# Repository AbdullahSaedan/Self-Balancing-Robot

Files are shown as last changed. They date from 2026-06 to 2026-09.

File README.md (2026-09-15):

# Self-Balancing Robot - Control Systems Project

https://github.com/user-attachments/assets/34fe275d-3d88-4c13-a9c5-a07f3246fb1b

A two-wheel self-balancing robot built from scratch — from first-principles dynamic
modelling and simulation to embedded control on hardware.

## Project Stages

-  **Stage 0** - Simulation of a single body pendulum: PID control, gain tuning, documented results
- **Stage 1** - Full coupled cart-pole simulation: explicit equations of motion, cascaded PID, pole placement analysis, state feedback control
-  **Stage 2** - Hardware design: Component selection, mechanical design, CAD, measurment of physical parameters
-  **Stage 3** - Embedded implementation: Microcontroller, IMU integration, sensor filtering, control on hardware, tuning

## Skills Demonstrated

- Dynamic modelling and equations of motion from first principles
- State-space modelling and full-state feedback control
- Pole placement design and closed-loop stability analysis
- PID control design with anti-windup and derivative on measurement
- Discrete-time simulation in Python
- Gain tuning and performance analysis
- Engineering documentation
- Complementary Filtering
- Gain scheduling

## Repository Structure

```
analysis/     Pole placement and recovery-limit analysis scripts
simulation/   Plant model, controllers, and simulation entry points
hardware/     Chasis Design, CAD and build documentation
embedded/     Arduino firmware - bringup and control
docs/         Derivations and results for every stage
tools/        Log parsing and plotting scripts
logs/         Raw captured runs from the robot
tools/        Log parsing and plotting scripts
```

## Results - Stage 0

*Nominal tuning — stable convergence within 0.5 seconds*

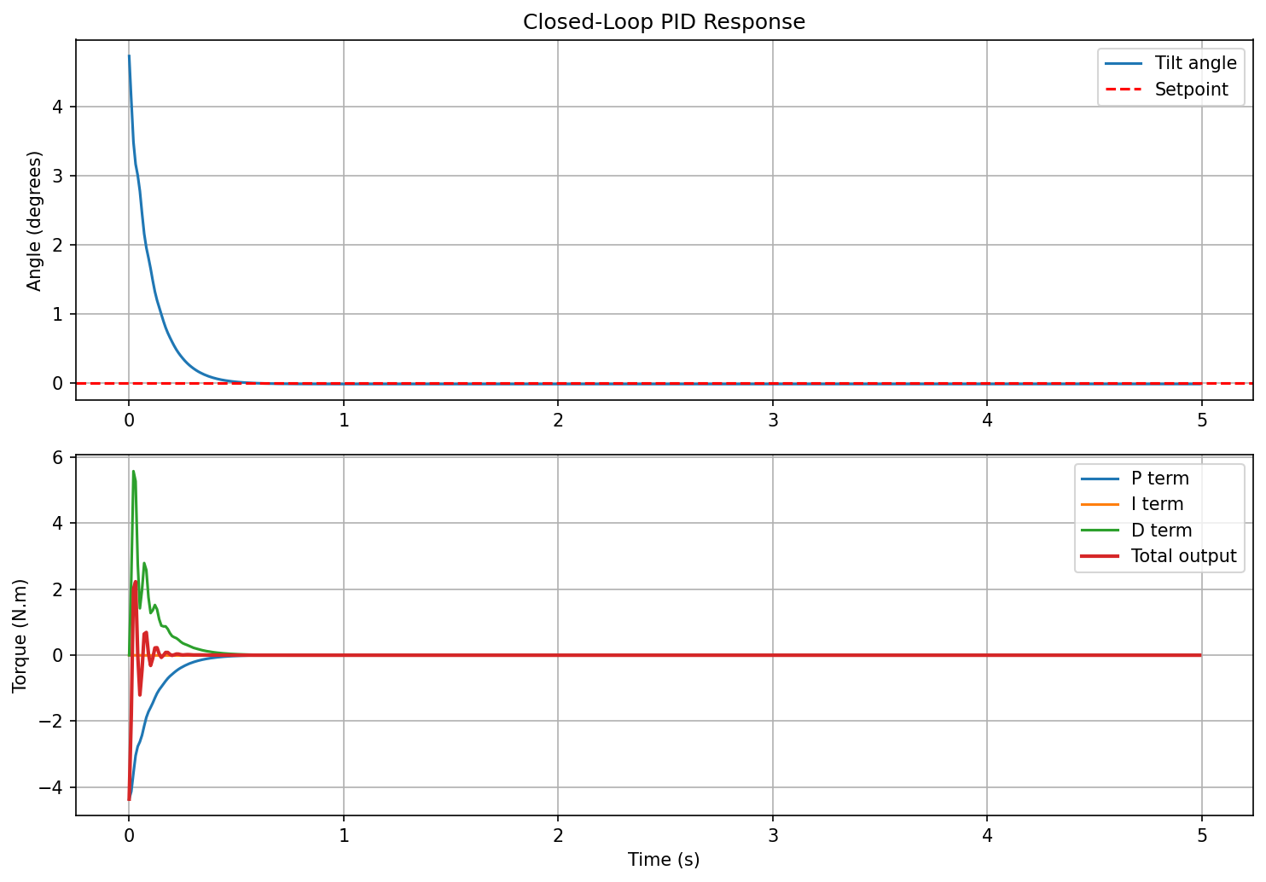
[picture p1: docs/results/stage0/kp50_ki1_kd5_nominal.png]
<br>

*Controller recovery limit — 5 N.m torque limit, all angles recovered but only up to 10° converge to zero*

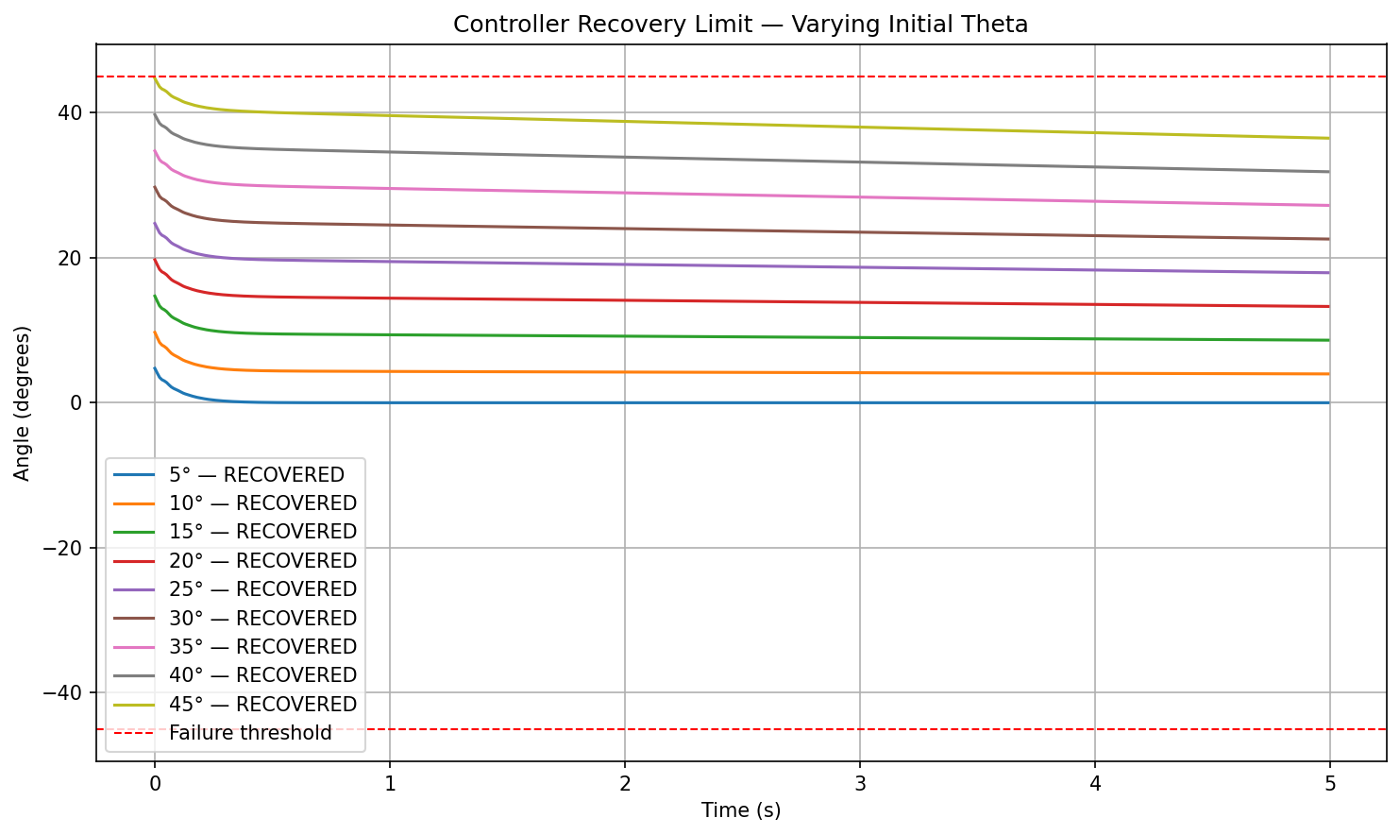
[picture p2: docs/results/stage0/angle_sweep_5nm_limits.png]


[View full Stage 0 results](docs/results/stage0/README.md)

## Results - Stage 1

*Cascaded PID — oscillates, does not fully converge*

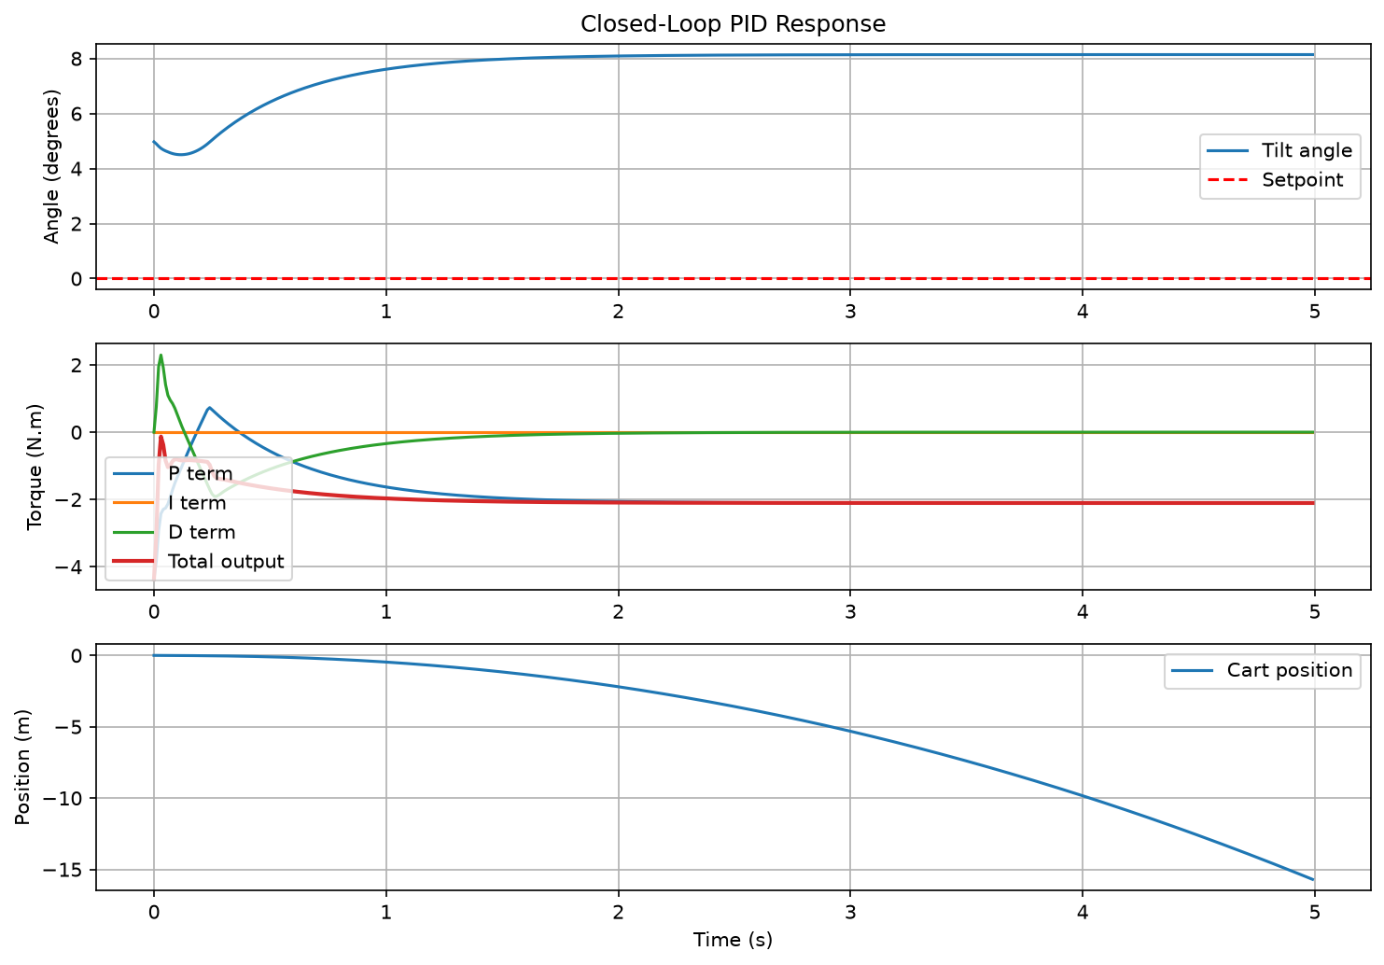
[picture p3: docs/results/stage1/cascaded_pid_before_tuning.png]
<br>

*State feedback with pole placement — converges to zero*

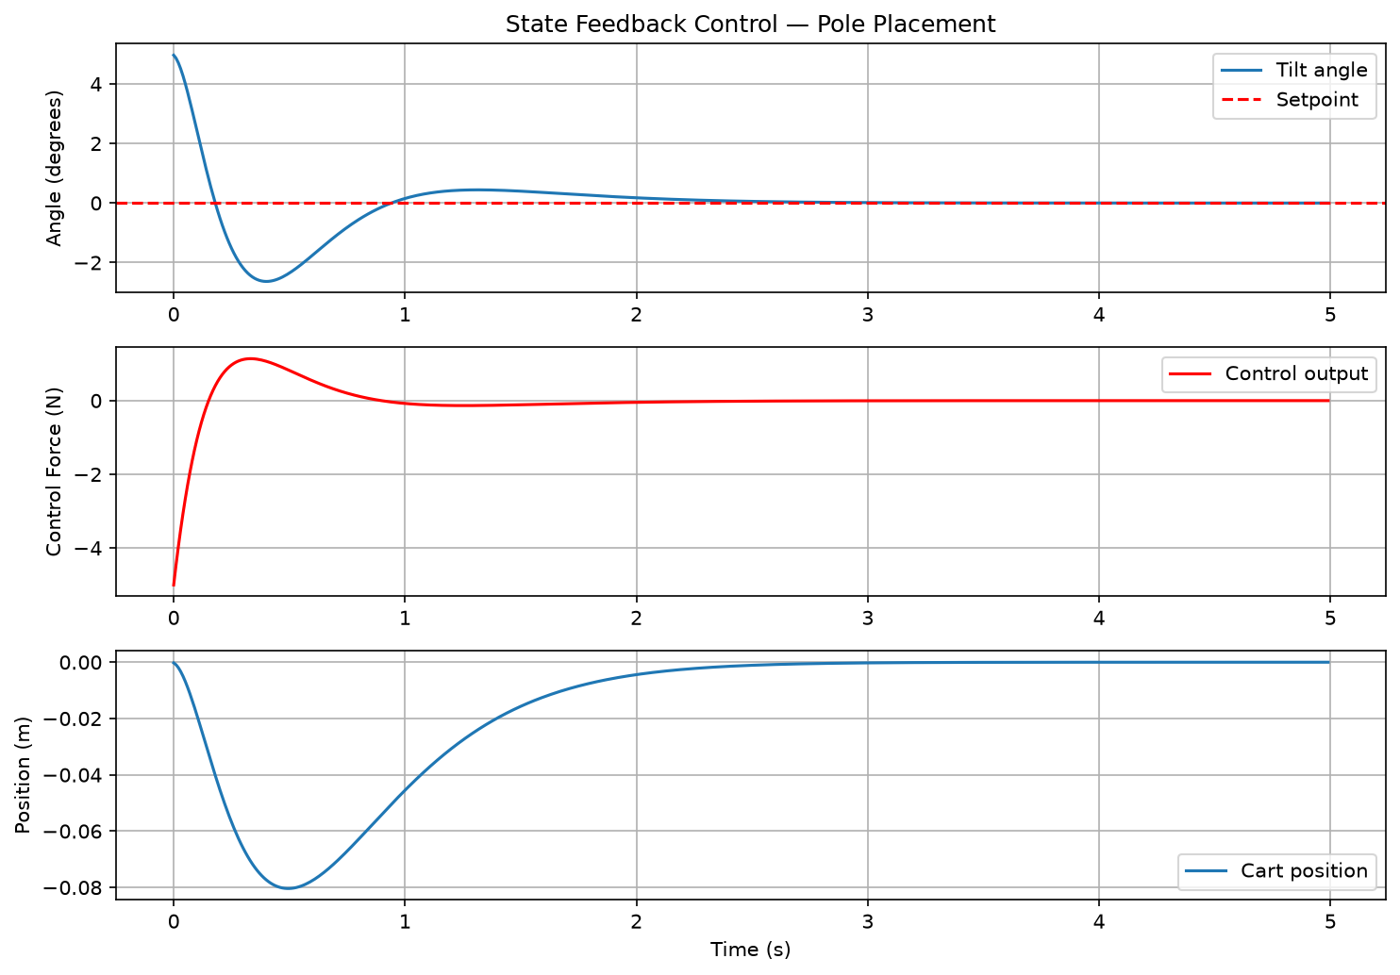
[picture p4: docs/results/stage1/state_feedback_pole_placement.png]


[View full Stage 1 results](docs/results/stage1/README.md)

## Results - Stage 2

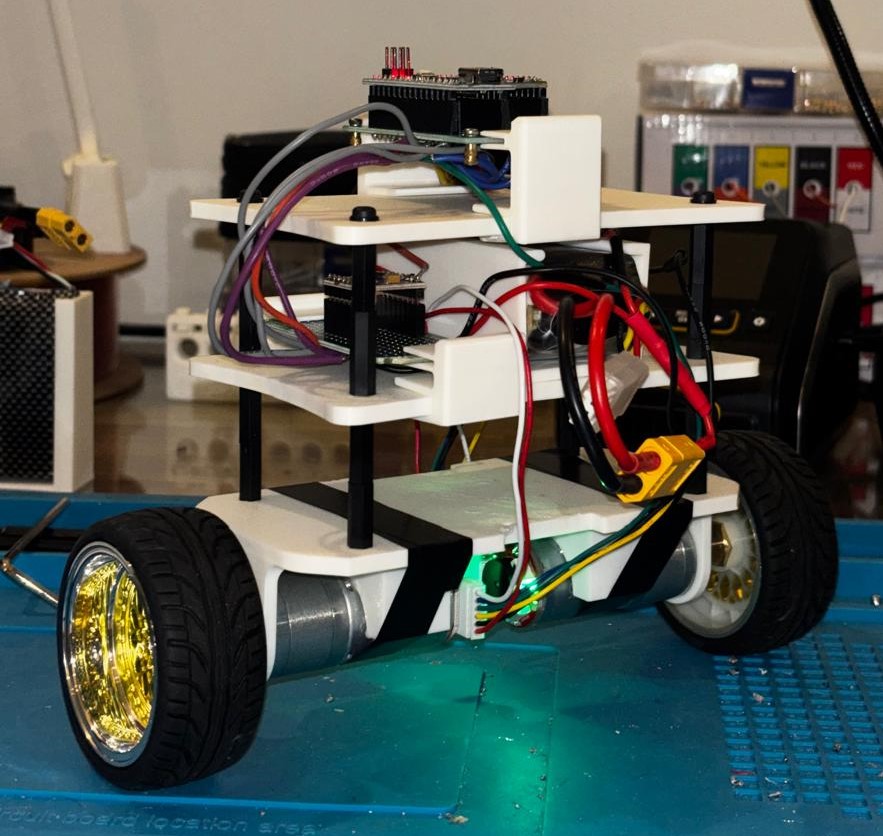
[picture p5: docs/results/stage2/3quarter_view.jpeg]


### Measured Physical Parameters

| Parameter | Symbol | Assumed (Stage 1) | Measured | Method |
|---|---|---|---|---|
| Body mass | m | 0.50 kg | 0.565kg | Scale |
| Wheel/base mass | M | 0.30 kg | 0.056kg | Scale |
| Pivot to COM height | L | 0.10 m | 0.043 | moment balance |
| Body inertia about COM | I | 0.006 kgm² | 0.00082 kgm² | Compound pendulum, 20 swings |

Stage 1 gains were recomputed from the measured values before hardware, this was implemended in stage 3.

[View full Stage 2 results](docs/results/stage2/README.md)

## Results - Stage 3

*Steady-state balancing - holds within ±2.0°, using under 16% of actuator authority*

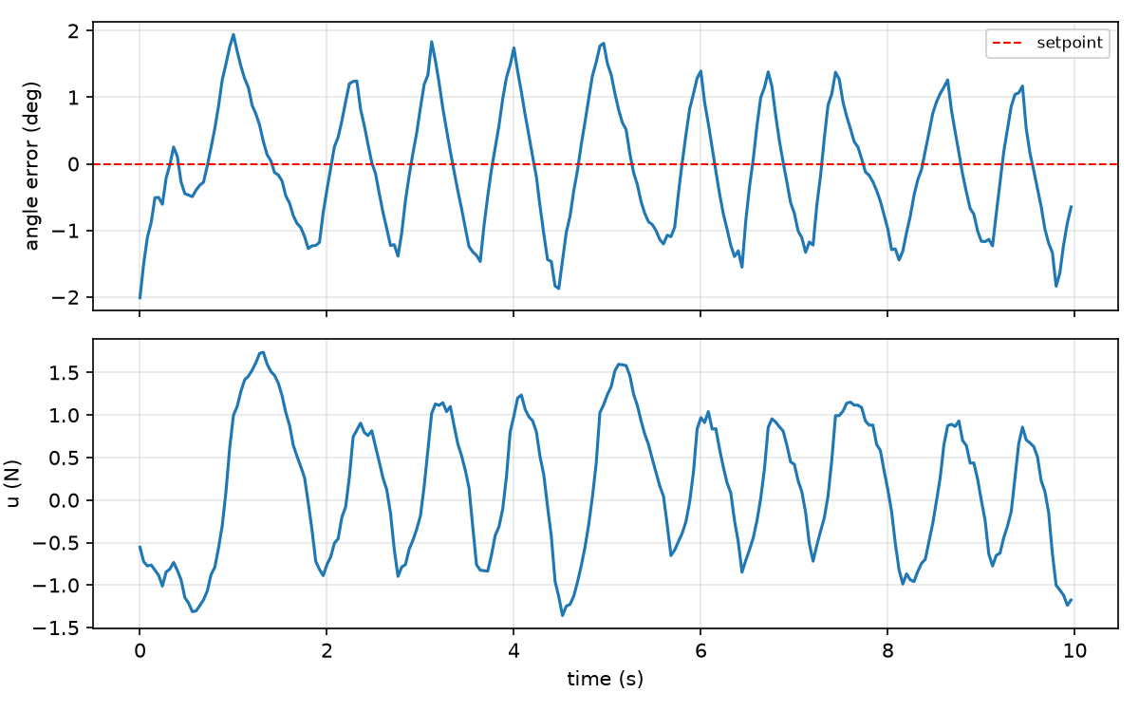
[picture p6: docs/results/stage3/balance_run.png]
<br>

*Disturbance rejection - scheduled velocity gain recovers from a 9.4° push, fixed gain falls from 2.2°*

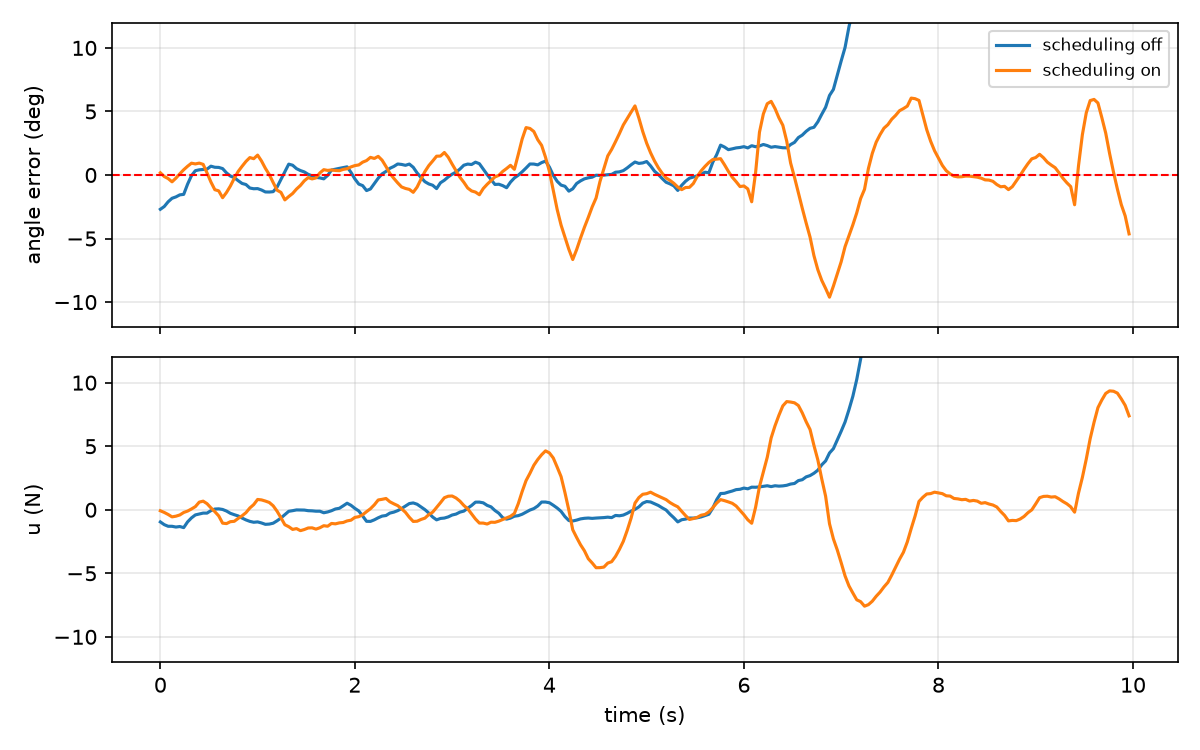
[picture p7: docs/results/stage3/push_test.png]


### Actuator Characterisation

U_MAX was measured at 11.1 ± 0.13 N by step response identification, against a
datasheet guess of 4.0 N. The same data revealed back-EMF drag of 26 N·s/m
missing from the Stage 1 plant, which was added before the gains were recomputed.

Three of the four gains are used exactly as derived from pole placement. The
velocity gain is the exception, reduced from 27 to 16 and scheduled back up
above 0.15 m/s.

[View full Stage 3 results](docs/results/stage3/README.md)

## Setup

Requires Python 3.12 or later.

```bash
git clone https://github.com/AbdullahSaedan/Self-Balancing-Robot.git
cd Self-Balancing-Robot
pip install -r requirements.txt
```

Run a simulation:

```bash
python simulation/simulate.py
python simulation/simulate_state_feedback.py
```

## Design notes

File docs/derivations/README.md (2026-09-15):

**Note:** this model has a single actuator. The applied horizontal force F is the only control input; there is no independent pivot torque. The motor's effect on the pendulum enters through the coupling term -mlẍcosθ rather than as a direct torque about the pivot. In the simulation code this input is named u.

# Equations of Motion

Derived from first principles using the Lagrangian method.

## Cart equation (horizontal motion)
(M+m)ẍ - mLθ̈cosθ + mLθ̇²sinθ = F(t)

## Pendulum equation (rotational motion)
(I+mL²)θ̈ - mLẍcosθ - mgLsinθ + bθ̇ = 0

Where:
- I = moment of inertia of the pendulum about its centre of mass (kg.m²)
- M = cart/wheel mass (kg)
- m = pendulum body mass (kg)
- L = distance from pivot to centre of mass (m)
- θ = angle from vertical (rad)
- F(t) = applied motor force (N)
- b = viscous damping coefficient (N.m.s/rad)

These are the full nonlinear coupled equations.
Stage 0 used a simplified single-body approximation as a first step.
These full coupled equations are implemented in Stage 1.

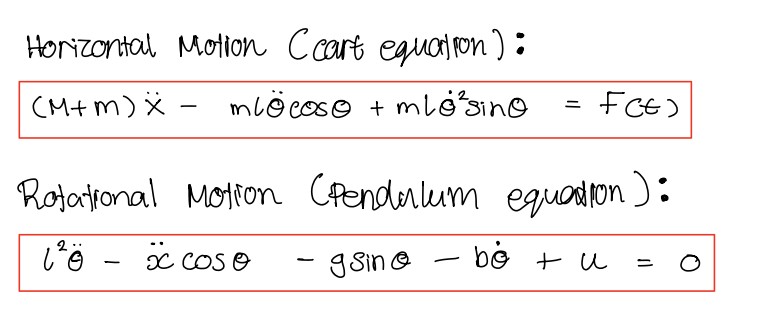
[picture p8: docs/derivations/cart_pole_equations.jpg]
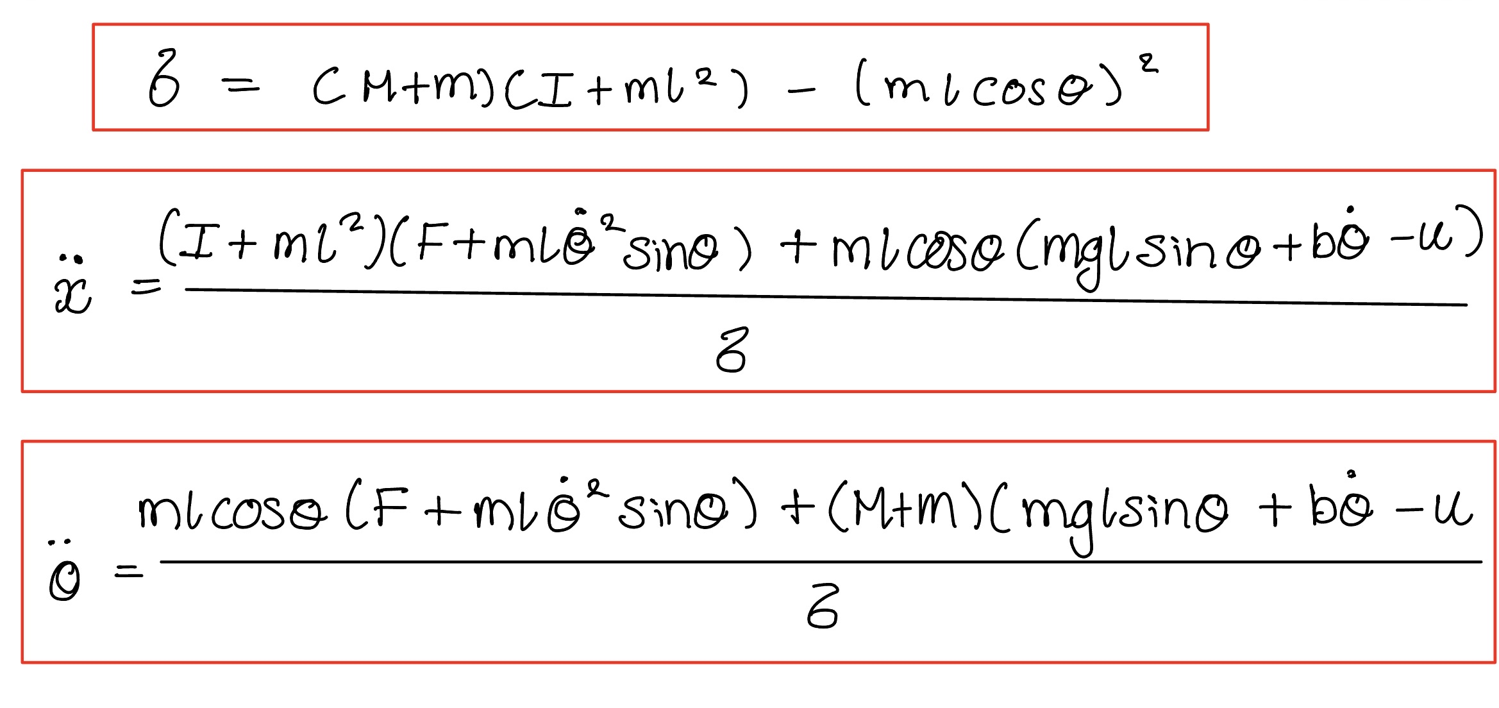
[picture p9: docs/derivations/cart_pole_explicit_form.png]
 

*Note: these images show the original hand derivation, which contained sign errors in the damping and centrifugal terms and incorrectly treated the control input as an independent pivot torque. The errors were identified through a dimensional consistency check and a physical sanity check on the open loop pole location, and propagated into the simulation code before correction. The equations above supersede the images.*

## Explicit form for simulation

The coupled equations above were solved simultaneously to eliminate the coupling terms and giving explicit expressions for both ẍ and θ̈ .

A shared denominator δ appears naturally from the algebra:

δ = (M+m)(I+mL²) − (mLcosθ)²

This represents the coupled inertia of the system. It varies with θ because the mechanical coupling between the cart and the pendulum changes with the angle.

ẍ = [(I+mL²)(F − mLθ̇²sinθ) + mLcosθ(mgLsinθ − bθ̇)] / δ

θ̈ = [mLcosθ(F − mLθ̇²sinθ) + (M+m)(mgLsinθ − bθ̇)] / δ

Where:
- δ = coupled inertia denominator
- I = moment of inertia (kg.m²)
- All other variables as defined above

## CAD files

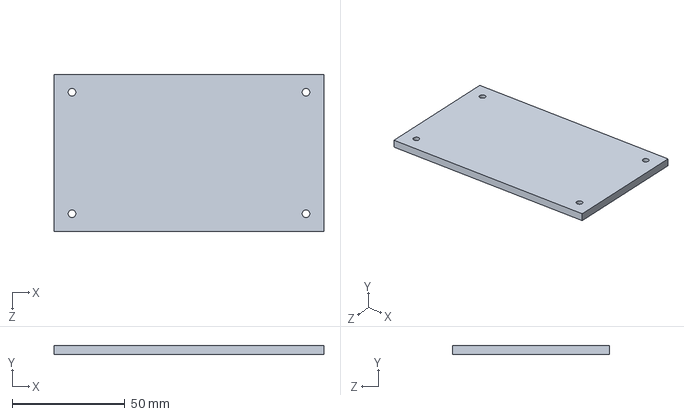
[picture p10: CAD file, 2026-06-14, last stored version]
hardware/CAD/platform.SLDPRT
120.0 x 4.00 x 70.0 mm

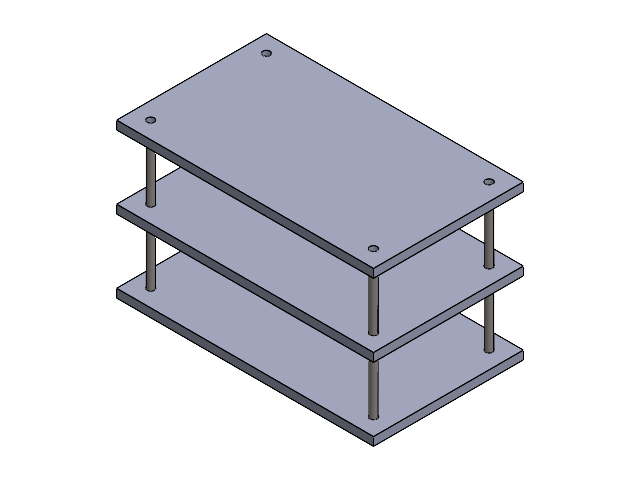
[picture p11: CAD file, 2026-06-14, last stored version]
hardware/CAD/chassis_assembly.SLDASM
platform x 3
socket head cap screw3_iso x 8

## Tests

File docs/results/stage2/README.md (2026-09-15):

# Hardware Design - Stage 2

## Build

*Assembled robot — three-quarter, top and side views*


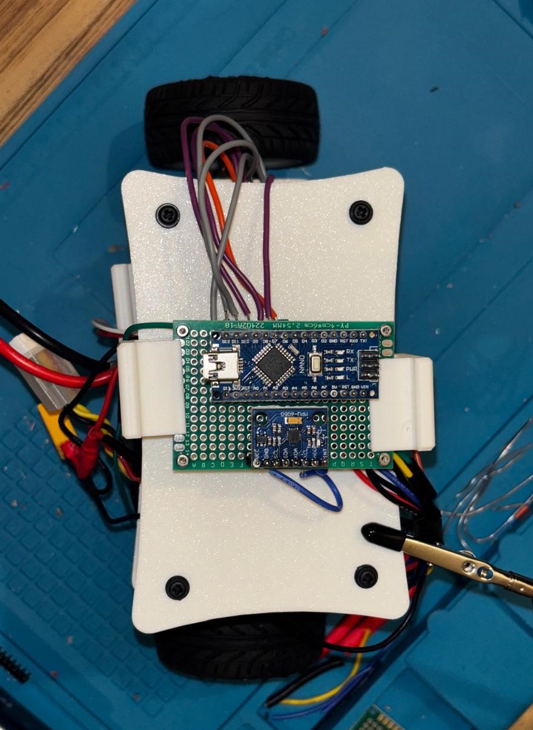
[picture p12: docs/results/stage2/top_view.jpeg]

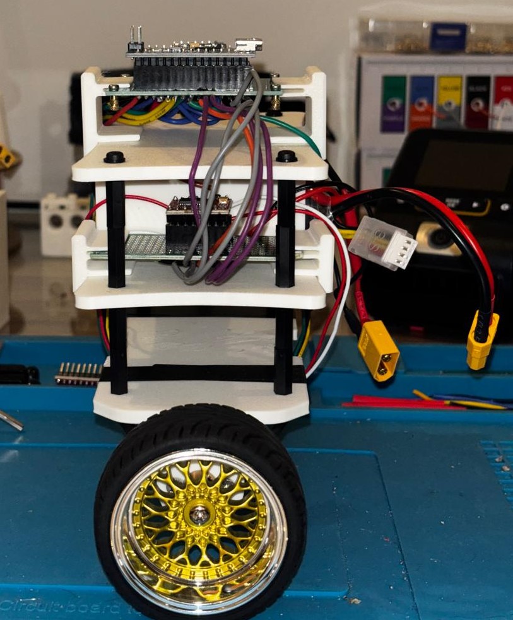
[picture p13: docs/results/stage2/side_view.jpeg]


## Component Selection

| Component | Qty | Key spec | Why chosen |
|---|---|---|---|
|**LM2596** |**1** |**Not in final build - see why under 'Electronics''**, ||
|Arduino Nano |1 |ATmega328P chip, 16MHz, 5V |Small footprint, widley available |
|MPU6050 IMU |1 |6-axis (3axis accelerometer, 3axis gyroscope), I2C |Measures both acceleration and rotation rate|
|TB6612FNG Driver |1 |Dual-channel, 1.2A continuous - 3.2A peak, 2.5-13.5V motor supply |Lower voltage drop than common alternatives (Important with 7.2v battery)|
|JGA25-370 |2 |12V, 170RPM - no load, integrated encoder, 1.2-1.8 stall |Integrated quadrature encoders provide the wheel position and velocity states required for full state feedback |
|Wheels - 65mm Diameter |2 |Rubber, 65mm diameter |Rubber for traction|
|2S LiPo |1 |7.4V, 1600mAh |Voltage within drivers range |

## Mechanical Design
### Chassis Layout

The chasis is a three-platform stack. The bottom platform has motor mounting brackets built into it, holding the motors beneath it, with the battery carried ontop. The middle platform holds the motor driver and buck converter. The top platform carries the perfboard with the Arduino nano and IMU, mounted centrally.

The battery was originally intended to be on the middle platform in order to avoid lowering center of mass, however a decision was made to mount it into a printed bracket for removability. The bracket takes up more space than the battery alone so space was only found for it in the bottom platform, this works against the stacks layout intent of raising it but was accepted in exchange for a removable battery.

### Printed Parts

*CAD source files for the chassis were lost in a hardware issue and have not been recreated. Printed parts remain in use and physical parameters were measured from the build assembly*

**Bottom Platform.** Printed as a single piece with the motor mounting brackets included in the geometry rather than as separate bonded parts. The brackets locate the motors at the front of the body only.

**Motor rear supports.** The integral brackets hold the motors at one end, leaving the rear of each motor unsupported. Because the motors are back-heavy, this caused the rear ends to slack under their own weight. A support was printed for each motor with a semicircular cutout matching the motor barrel radius, bonded to both the platform and the motor body. This constrains the rear of the motor and eliminates the issue.

**Battery bracket.** A printed enclosure glued to the bottom platform, holding the LiPo. The front face is left open so the battery slides in and out, and the top face is reduced to narrow lips along each side, retaining the battery vertically while leaving most of the top open to reduce excessive friction.

**Perfboard clips.** The top perfboard is populated with wiring on its underside, so it cannot sit flush against the platform. Friction-fit clips were printed to engage both the platform and the perfboard, standing it off far enough to clear the wiring beneath. Using a friction fit rather than glue means the perfboard can be lifted off for access without breaking the mounting. 2 clips were added one on each side near the edge of the platform.

### Assembly
The three platforms are joined by nylon M3 standoffs at [X]mm spacing.

The middle perfboard is mounted using four small M3 standoffs, glued to the platform and passing through the 4 corner holes with a screw ontop of each. The top perfboard uses friction-fit clips instead, which was the later and better approach since it avoids the bonded joint and allows the board to be lifted off. However, omponents on both boards are socketed on headers rather than soldered directly, so they remain accessible for replacement regardless of how the board itself is mounted.

Motors are fastened into the integral brackets with screws.

## Electronics
### Power Architecture
An LM2596 buck converter originally supplied the 5V rail. It was removed. Taking VCC from the Nano's own 5V rail means the driver's logic supply and its logic signals always come from the same source; with a separate converter there is a state in which battery is disconnecte and USB is connected, where the Nano drives the driver's inputs while its VCC sits at 0V. Two motor drivers were lost before this was identified.

The 2S LiPo supplies two separate rails. Motor power is taken directly from thebattery to the TB6612FNG's VM input. The battery also feeds the Arduino Nano's VIN, whose onboard regulator produces the 5V rail supplying the MPU6050, the encoders, and the driver's logic input (VCC) — allowing one battery to fulfil both voltage requirements.

The rails are also separated because, motors need rapidly switching currents which causes noise. Sharing a supply between the motors and the sensor electronics would couple that switching noise into the IMU readings, which the control loop depends on.

All subsytems share a common ground. This is because the driver interprets the Nano logic reletive to its own ground reference, so in order to keep the logic consistent they must have the same reference point.

The IMU is mounted on the top platform, physically separated from the driver on the middle platform. The driver is a noise source, so distance between it and the sensor is a design choice.

### Wiring
#### Arduino Nano

| Pin | Connects to | Function |
|---|---|---|
| D2 | Motor A encoder channel A | Encoder input |
| D3 | Motor B encoder channel A | Encoder input |
| D4 | Motor A encoder channel B | Encoder input |
| D5 | Motor B encoder channel B | Encoder input |
| D6 | TB6612 STBY | Driver enable |
| D7 | TB6612 AIN1 | Motor A direction |
| D8 | TB6612 AIN2 | Motor A direction |
| D9 | TB6612 PWMA | Motor A speed |
| D10 | TB6612 PWMB | Motor B speed |
| D11 | MPU6050 INT | IMU interrupt |
| D12 | TB6612 BIN1 | Motor B direction |
| D13 | TB6612 BIN2 | Motor B direction |
| A4 | MPU6050 SDA | I2C data |
| A5 | MPU6050 SCL | I2C clock |
| D0, D1 | Reserved for USB serial | Not connected |

#### Power

| From | To | Wire |
|---|---|---|
| Battery + | TB6612 VM |
| Battery + | Buck IN+ |
| Battery - | Buck IN- |
| Buck OUT+ (5V) | TB6612 VCC |
| Buck OUT+ (5V) | Nano 5V pin |
| Buck OUT+ (5V) | Encoder VCC, both motors |
| Buck OUT+ (5V) | MPU6050 VCC |

#### Motor outputs

| TB6612 | Motor | Wire |
|---|---|---|
| AO1 | Motor A + |
| AO2 | Motor A - |
| BO1 | Motor B + |
| BO2 | Motor B - |

## Physical Parameters

| Parameter | Symbol | Assumed (Stage 1) | Measured | Method |
|---|---|---|---|---|
| Body mass | m | 0.50 kg | 0.565kg | Scale |
| Wheel mass | M | 0.30 kg | 0.056kg | Scale |
| Pivot to COM height | L | 0.10 m | 0.043 | moment balance |
| Body inertia about COM | I | 0.006 kgm² | 0.00082 kgm² | Compound pendulum, 20 swings |

[View Stage 3 results](../stage3/README.md)

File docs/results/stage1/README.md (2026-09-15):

# Simulation Results - Stage 1

**Note on parameters:** The physical parameters used throughout Stage 1 - cart and pendulum mass, pendulum length, and the torque limit are nominal values chosen before hardware selection. They do not represent the measured properties of the robot being built. Open loop pole locations, gain values and settling times therefore describe the model rather than the physical system. Simulations will be re-run with measured parameters once characterisation is complete in Stage 2.

## Angle Only PID

With the full coupled cart-pole model implemented, the same angle-only PID from Stage 0 was tested. Unlike Stage 0 where cart motion was not modelled, the cart is now free to drift.

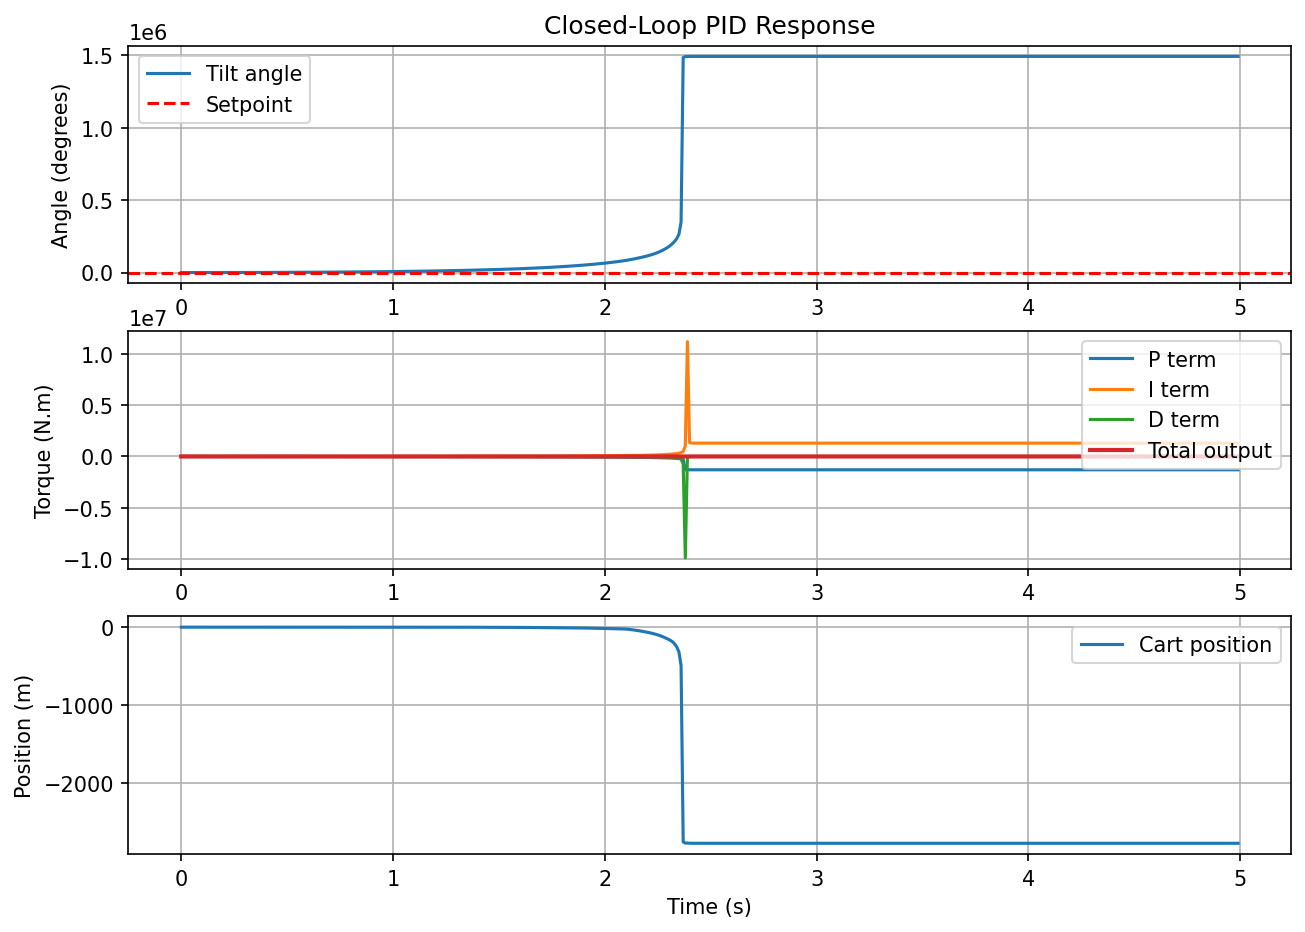
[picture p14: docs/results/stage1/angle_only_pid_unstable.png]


The system goes unstable - the angle explodes to 10⁶ degrees and the cart drifts to -2500m, essentially meaning both are heading to infinity - the pendulum has fallen.

This behaviour is expected since the PID controller is only controlling the angle and is not accounting for cart drift. This shows that a second PID is needed to control the cart's position.

## Cascaded PID - Before Analytical Tuning

To control both angle and cart position simultaneously, a cascaded PID structure was implemented. An outer position PID computes a target angle setpoint, which is fed into an inner angle PID that produces the control force. Gains were tuned manually.



The cascaded PID fails to regulate cart position. The angle settles at a constant 8.1 degrees with a constant control output of -2.1 N, while the cart accelerates away continuously, reaching -15.7m within 5 seconds. The system finds a runaway equilibrium where a constant tilt and constant force balance while the cart accelerates without bound. It is almost impossible to fully stabilise this way because correcting angle affects position and correcting position affects angle. This is because the two PIDs were designed independently without accounting for the mathematical coupling between cart and pendulum dynamics.

## Pole Placement Analysis

Before implementing state feedback, the open loop poles of the system were computed using the linearised A matrix from plant.py:

Open loop poles: [ 0, 0, 6.22, -7.89]

The positive pole (6.22) confirms the system is naturally unstable - the pendulum will fall without control. The two poles at zero correspond to the cart states, confirming the cart drifts indefinitely without correction.

Desired closed loop pole locations were arrived at iteratively. Poles must lie in the left half plane for stability, and were placed relative to the open loop unstable pole at 6.220. Successive sets were tested in simulation and evaluated on settling time and peak control force: poles placed further left converged faster but demanded more force. [-3, -4, -5, -6] was retained as the fastest response that stayed within a reasonable force budget.

The pole placement algorithm computed the required state feedback gain matrix:

K = [57.33, 8.15, -11.01, -10.83]

Where each value corresponds to the gain on θ, θ̇, x, and ẋ respectively.

## State Feedback Control - Pole Placement Result

Using the gain matrix K computed from pole placement, state feedback control was implemented in `simulate_state_feedback.py`. The control law replaces the entire cascaded PID with a single equation:

u = -(K[0]·θ + K[1]·θ̇ + K[2]·x + K[3]·ẋ)

All four states are used simultaneously to compute the control force, accounting for the coupling between cart and pendulum that the cascaded PID struggled with.



Using state feedback control stabilised the system. The angle starts at about 4.5 degrees, undershoots to -2.6 degrees, and converges to the setpoint within approximately 2.5 seconds. Peak control force is 5 N at the start of the correction, decaying to zero as the system settles. The cart moves a maximum of 0.08m from the origin before returning to it - a significant improvement over the cascaded PID, which failed to regulate position at all.

[View Stage 2 results](../stage2/README.md)

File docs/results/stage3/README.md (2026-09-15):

# Stage 3 — Embedded Implementation

Closing the loop on hardware. Bring-up constants, pin map and wiring are in Stage 2. This stage covers the actuator measurement that corrected the plant model, the recomputed gains, and the measured balancing performance.

Code was written with AI assistance for C and Arduino idiom. The control design, measurements, system identification and debugging are my own work.

## Actuator characterisation

The firmware converts force to duty as duty = u / U_MAX × 255. U_MAX is the scale factor between the newtons the controller computes and the PWM actually delivered, so an error in it multiplies every gain equally. It had been carried as a datasheet guess of 4.0 N, changed to 2.77 then later replaced by 11.1 N (see method below).

### Method

The robot was laid flat on a bottlecap used as a skid and driven from standstill at full duty, with distance logged from the encoders. Ten runs.

The step response of the drivetrain is first order. Fitting it across the full run gives v_max and τ, from which a₀ = v_max / τ. This is more reliable than measuring the initial slope by hand, where few samples and a small displacement leave the encoder noise dominating.

| Parameter | Fitted | Meaning |
|---|---|---|
| a₀ | 17.7 m/s² | Acceleration at t = 0, full force available |
| v_max | 0.43 m/s | Top speed, force decayed to zero |
| τ | 24 ms | Time constant of the decay |

```
U_MAX = m · a₀ = 0.625 × 17.7 ≈ 11.1 N
```

**`U_MAX` = 11.1 ± 0.13 N** over ten runs. Agreement ±1.2%, fits tracking the data to 0.12 mm RMS.

Friction was neglected. The full form is U_MAX = m·a₀ + F_friction, and friction only reduces observed acceleration, so 11.1 N is a lower bound. Skid friction puts the true figure near 12 N. The firmware uses 11.1 N, because the skid friction belongs to the test rig and is not present while balancing.

The fit also gives the drag. Force falling from 11.1 N at standstill to zero at 0.43 m/s is back-EMF acting as viscous damping, b_drive = m / τ ≈ 26 N·s/m. The Stage 1 plant treats u as a pure force, so this term was added to plant.py before the gains were recomputed.

## Control design

The measured b_drive was then set in plant.py, so the model includes the back-EMF drag the Stage 1 plant omitted. Stage 1 results were produced before this term existed and reflect the undamped model.

Motor force becomes F = u - b_drive · ẋ. That term enters both the ẍ and θ̈ rows of A, since they are coupled through the cart equation.

### Effect on the derived gains

Pole placement at [-15, -18, -0.7, -0.9], using the Stage 2 measured
parameters:

| | Without drag | With b_drive = 26 |
|---|---|---|
| K[0] | 13.703 | 13.703 |
| K[1] | 0.879 | 0.879 |
| K[2] | -0.405 | -0.405 |
| K[3] | -1.079 | -27.079 |

Only the velocity gain changes, and it changes by exactly 26.000. This is the expected result rather than a coincidence since F = u - b·ẋ.

### Firmware gains

```cpp
const float K[4] = { 13.703f, 0.879f, 0.405f, 16.000f };
```

K[0], K[1] and K[2] are used exactly as derived. K[3] was reduced experimentally from the derived 27.079 down to 16, which took steady-state angle from ±12° to ±1° and position wander from roughly 1 m to ±0.5 cm.

### Speed Scheduling

| Constant | Value |
|---|---|
| K3_FAST | 26.0 |
| V_BLEND | 0.15 m/s |

K[3] blends from 16 at standstill to 26 above V_BLEND. Recovery from a push is a force balance where the angle term has to beat the residual motor drag with the wheels already moving. One fixed gain cannot be both calm at standstill and authoritative during a recovery.

V_BLEND = 0.15 m/s was found by experiment. Raising it to 0.5 causes loss of balance, while disabling the schedule entirely does not, so the constant is not a simple threshold that can be relaxed. An intermediate blend appears to be worse than either endpoint, which suggests the issue is the rate at which k3 tracks velocity rather than the threshold itself. This has not been investigated further.

### Sign inversion

The simulation and the robot use opposite θ conventions, so K[2] and K[3] are sign-flipped between the two. K[0] and [1] are not. The firmware therefore applies +u where the simulation uses u = -Kx.

This was found late. The outer loop had been running inverted through earlier development before the discrepancy was traced.

## Firmware constants

Everything the control law depends on that is not a gain.

| Constant | Value |
|---|---|
| THETA_OFFSET | 0.0365 rad |
| DEADBAND_L | 19 |
| DEADBAND_R | 12 |
| GYRO_LPF | 0.15 |
| VEL_LPF | 0.15 |
| TAU | 0.5 s |
| Loop rate | 200 Hz |

THETA_OFFSET is the mean theta from a logged balanced run rather than a static measurement. Rolling resistance makes the apparent balance point direction-dependent, so a value taken from one direction alone is biased.

TAU is the complementary filter time constant. Neither sensor gives the angle alone, since the gyro is smooth but drifts as its bias integrates, while the accelerometer knows true vertical but reads motor vibration as tilt. TAU sets the split between them, trading noise against drift.A consequence is that a residual gyro bias of delta produces a steady angle error of delta multiplied by TAU. At 0.5 s, a bias error of 1 deg/s becomes half a degree of standing error, which is why the calibration value is checked at every boot.

GYRO_LPF smooths the rate term, separate from the complementary filter. The controller uses gyro rate directly for damping, and the raw signal is noisy enough that K[1] amplifies it into audible chatter. Each cycle the filtered value moves 15% toward the new reading, so noise averages out while real changes still come through. The cost is phase lag, which weakens the damping and is one candidate for the residual oscillation. Set by hand, smoothed only as far as the chatter required.

## Logging

Runs are captured untethered to stop the connected wire from effecting the run, so the log cannot be streamed over serial.

Samples are written to a RAM buffer placed in a .noinit section, which is not cleared by the warm reset that occurs when the serial port is opened. The robot runs free, is picked up and plugged in, and the buffer is dumped on the next boot.

The buffer holds 10 seconds at 25 Hz, recording e and u as int16. Every figure below came from these logs.

## Results

### Steady State Balancing



The robot balances indefinitely, holding within ±2.0 degrees of the balance point with an RMS of 0.94 degrees. Control effort peaks at 1.74 N against 11.1 N available, under 16% of actuator authority.

Control effort stays within ±1.2 N against 11.1 N available, under 11% of actuator authority. Force is not the constraint.

Three candidate mechanisms were tested and eliminated. Raising U_MIN across three values changed nothing, ruling out the low-force deadband. Increasing GYRO_LPF from 0.15 to 0.3 made the oscillation slightly larger rather than smaller, ruling out filter phase lag. The force headroom above rules out saturation.

That leaves gearbox backlash, measured at roughly 2.5 degrees, which is the same order as the oscillation amplitude. A correction must cross the gear slop before reaching the wheels, so it arrives late and overshoots. This is a mechanical limit rather than a control one, and no gain or filter setting removes it.

### Steady State Comparison for Velocity Gains

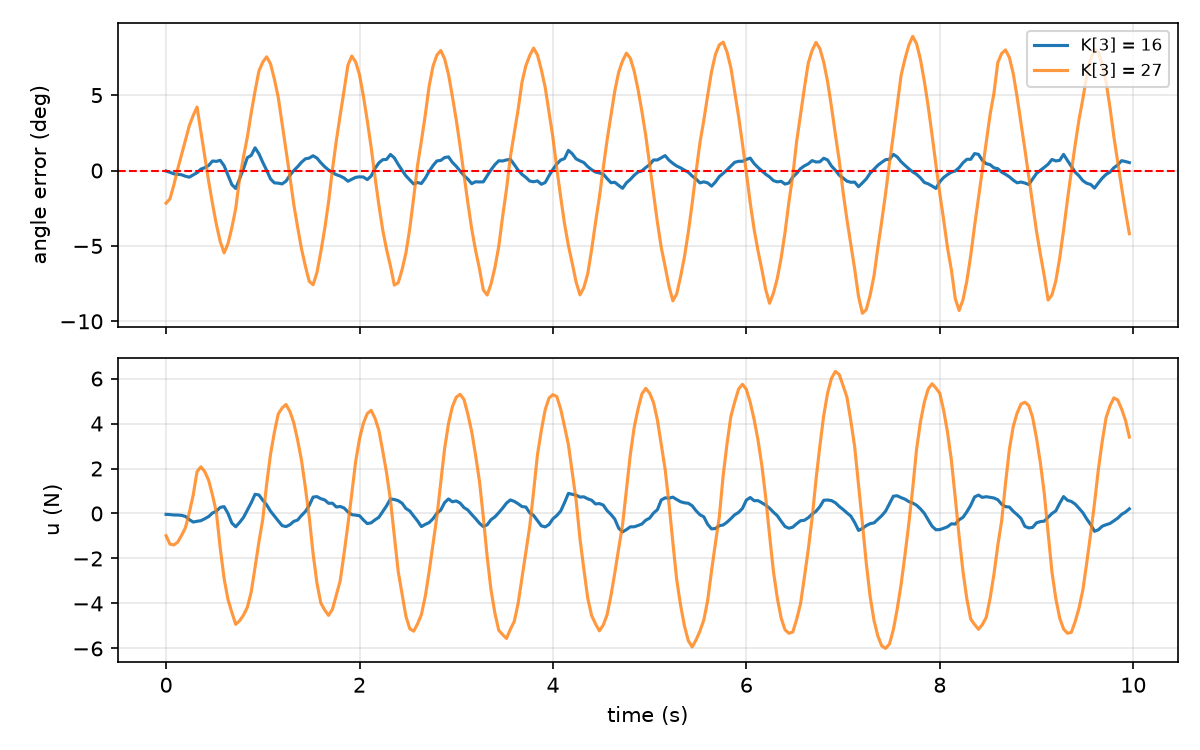
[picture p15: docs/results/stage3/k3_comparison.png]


Raising K[3] from 16 to 27 increases angle RMS from 0.62 to 5.38 degrees and control effort from 0.45 to 3.78 N RMS. Both scale by roughly the same factor, and even at 27 the effort stays within a third of the 11.1 N available, so the degradation is not a force limit.

### Push Test



Both runs use identical gains and differ only in whether the velocity gain is scheduled. With scheduling disabled the robot fails to recover from a 2.2 degree tap at 5.7 s and falls. With scheduling enabled it recovers from three disturbances, the largest reaching 9.4 degrees, returning to the setpoint within about 1.5 s each time.

The control effort traces show the mechanism. Without scheduling the commanded force stays near 2 N through the second after the tap, which is not enough to run the wheels out under the falling body. It only exceeds 11.1 N once the robot is already past recovery, and that command is beyond what the actuator can deliver. With scheduling, K[3] blends up as the wheels accelerate, and the controller commits 8.5 N at the moment of the disturbance rather than after it.

## Where this leaves the build

## Where this leaves the build

The robot balances indefinitely and recovers from disturbances up to roughly 9 degrees. The residual limit cycle of ±0.7 degrees is mechanical rather than a control problem, and removing gearbox backlash is the only change likely to reduce it.

Three of four gains are used exactly as derived from the model. The velocity gain is the exception, reduced from 27 to 16 for steady-state behaviour and scheduled back up above 0.15 m/s for recovery.

Stage 4 compares logged runs against the simulation directly, using release tests from a known initial angle so both sides start from the same condition.

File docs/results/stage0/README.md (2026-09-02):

# Simulation Results - Stage 0

**Note on parameters:** the plant parameters and torque limits used in Stage 0 are
nominal values chosen before hardware selection. They do not represent the measured
properties of the robot being built. Gain values, settling times and recovery ranges
therefore describe the model rather than the physical system.

## Nominal - Kp = 50, Ki = 1, Kd = 5

Starting from a 5 degree initial tilt, the controller should drive the angle back to zero and hold it there without clear overshoot or oscillation.


<br>
The tilt angle converges to the setpoint within 0.5 seconds with no overshoot. The <b>P</b> term starts negative and converges to 0 since the controller output needs to push the system back towards the setpoint. The <b>D</b> term initially spikes since the rate of change of measurement is highest at the start, then dies away as the system slows down approaching the setpoint. The <b>I</b> term is negligible since there is not enough accumulation of error, indicating that <b>P</b> and <b>D</b> alone are sufficient for these conditions.
<br>

## Low Proportional Term - Kp = 5, Ki = 1, Kd = 5

Reducing Kp caused the correction to be a lot weaker. Because of this the controller struggles to reach exactly zero and settles with a persistent steady state error.

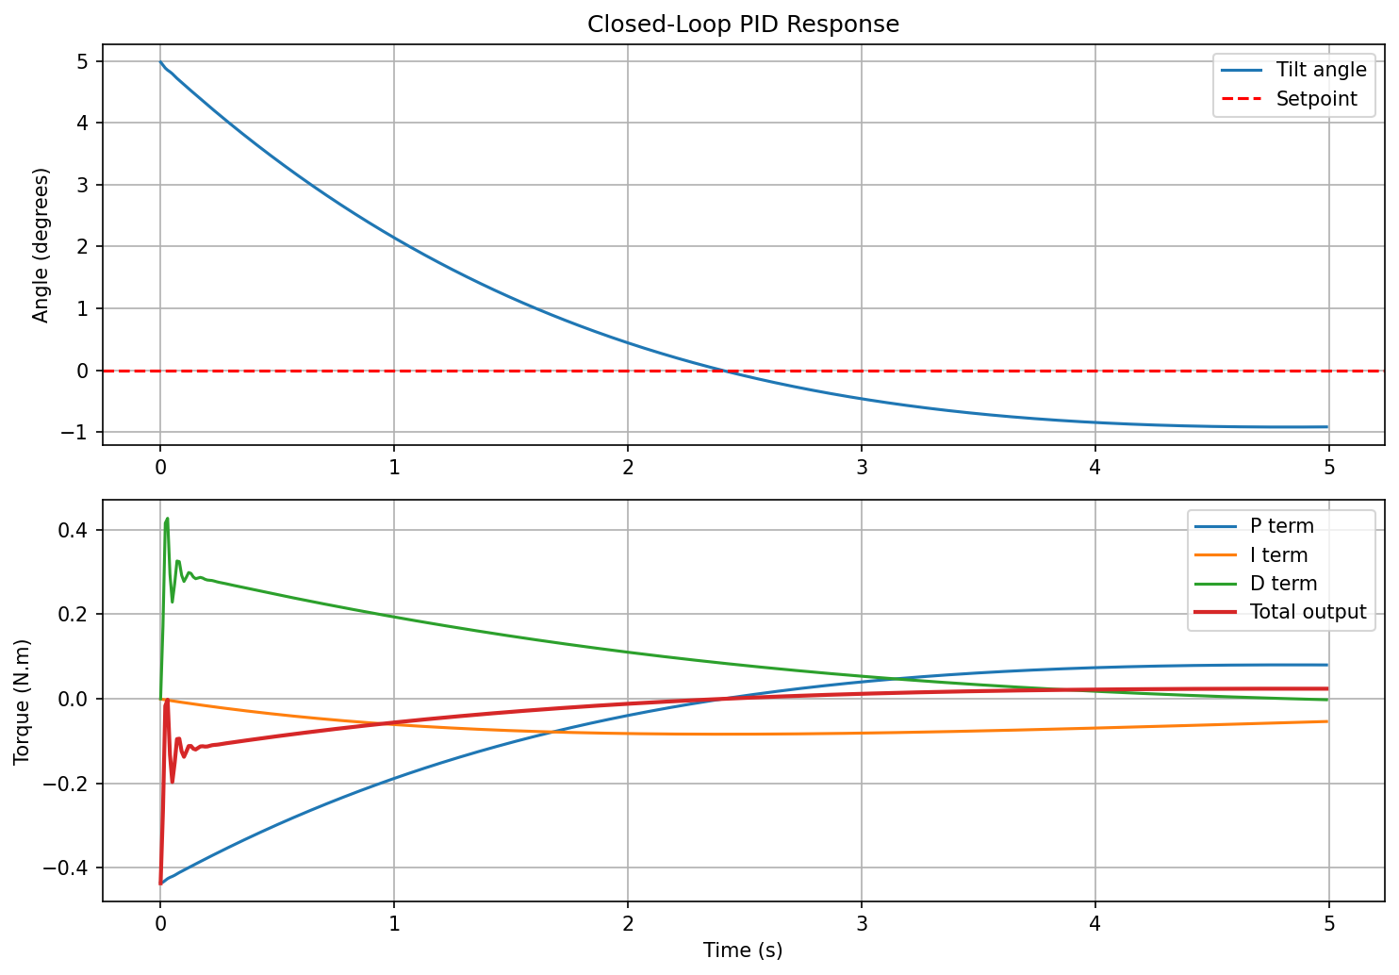
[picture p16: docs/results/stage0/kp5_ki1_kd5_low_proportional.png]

<br>
The steady state error is almost 1 degree and the torque remains small throughout since <b>P</b> is small. <b>P</b> correction is proportional to error so as the error decreases the correction becomes weaker and gravity takes over, causing the system to settle before reaching the setpoint. The <b>I</b> term grows slowly after 2 seconds because the error is constant and accumulates over time. The <b>D</b> term is present at the start since measurements are changing, then fades away as the angle becomes constant, because the rate of change of measurement decreases exponentially eventually reaching zero.
<br>

## No Derivative Term - Kp = 50, Ki = 1, Kd = 0

With <b>Kd</b> set to 0 the braking force is removed. The system is expected to overshoot continuously and never settle.

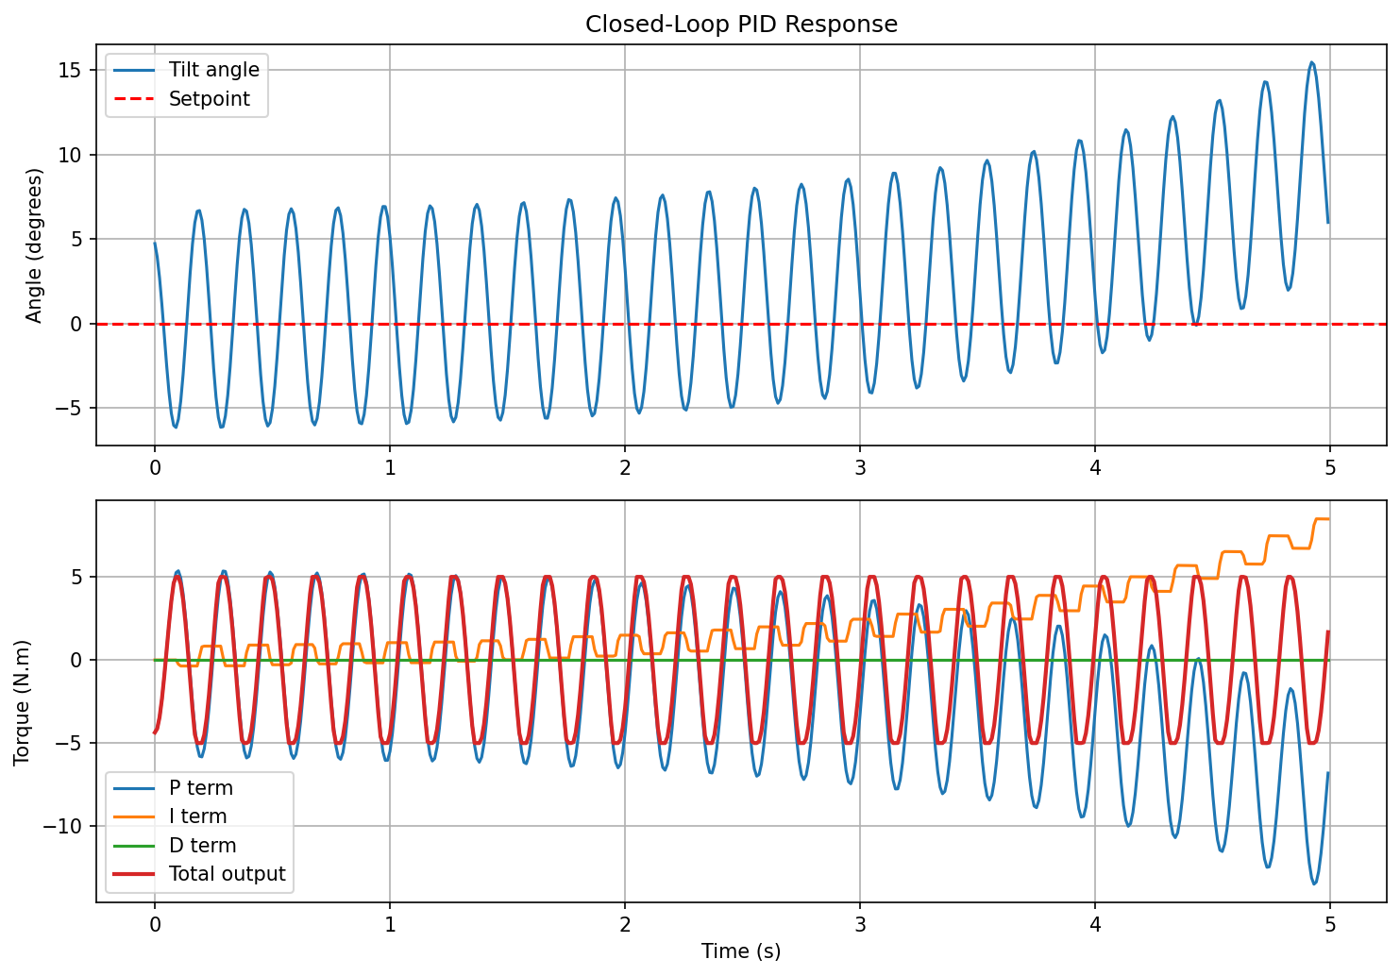
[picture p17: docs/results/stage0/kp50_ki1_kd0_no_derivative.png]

<br>

Since there is no derivative term there is nothing to dampen the overshoot, so the angle and torque oscillate continuously while accumulating error over time. The <b>P</b> term oscillates in phase with the tilt angle, continuously commanding corrective torque but never damping the motion due to the absence of the <b>D</b> term. This is why the <b>I</b> term grows steadily. The oscillation also grows over time, meaning on real hardware the robot would wobble with increasing amplitude until eventually becoming unstable.

## Controller Recovery Limit - Varying Initial Theta

Two runs were performed with different motor torque limits to assess controller recovery range.

### 5 N.m torque limit


<br>

With generous torque limits all angles up to 45° are classified as recovered, however only angles up to approximately 10° fully converge to zero. Larger angles settle with persistent steady state error that grows with initial angle.

### 1 N.m torque limit

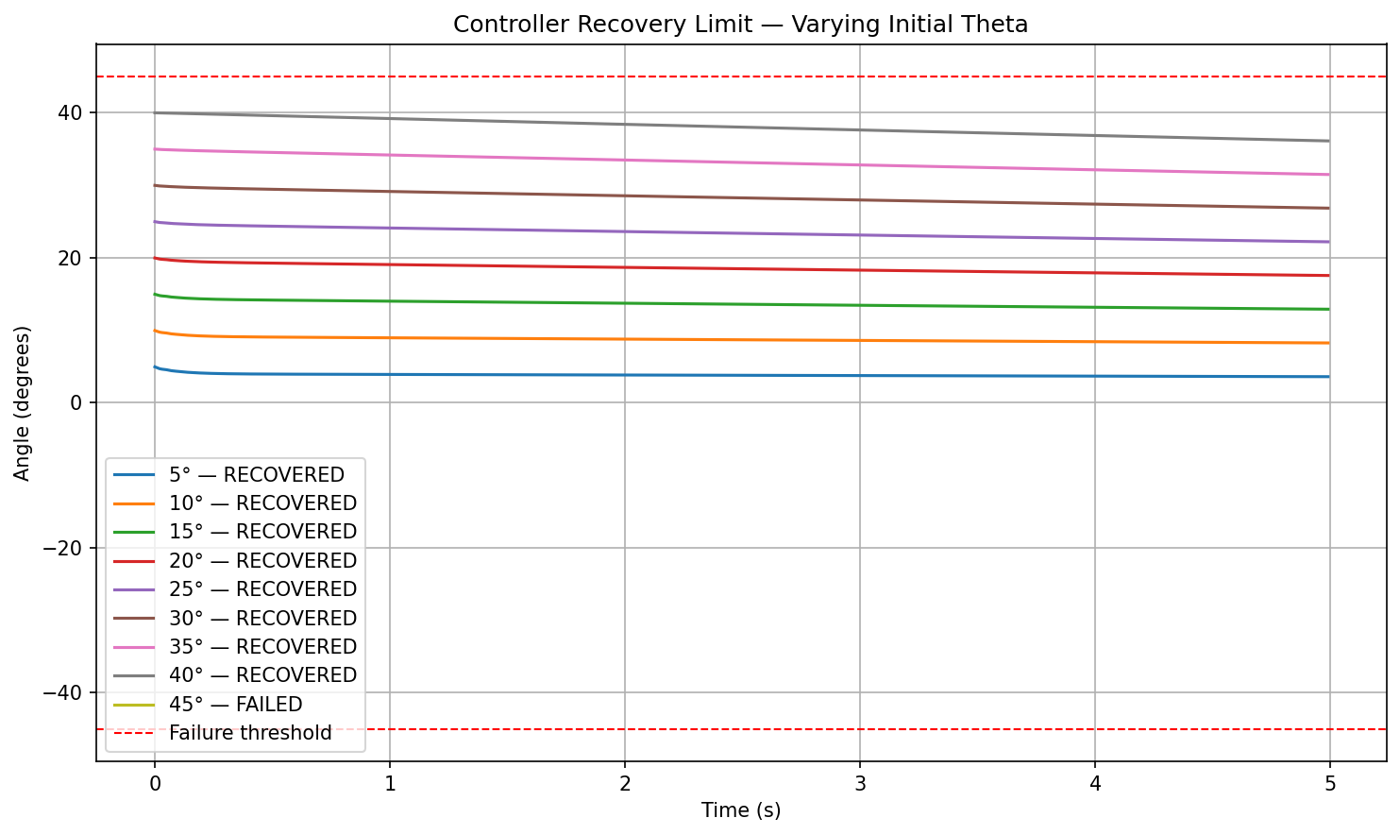
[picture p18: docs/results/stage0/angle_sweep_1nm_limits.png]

<br>

With more realistic torque limits the recovery range reduces further and steady state error is more pronounced. The 45° case fails entirely.

### Conclusion

Both results expose a fundamental limitation of the single-body simplified plant - without cart motion there is no physical mechanism to fully correct large angle errors. This is addressed in Stage 1 with the full coupled cart-pole model.

[View Stage 1 results](../stage1/README.md)

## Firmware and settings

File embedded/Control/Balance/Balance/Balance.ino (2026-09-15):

/* balance.ino - two-wheeled self-balancing robot, state feedback
   u = K[0]*e + K[1]*theta_dot_f + K[2]*pos + k3*vel_f

   Normal operation prints only the boot banner and ARM / FELL lines.
   Uncomment testModeBegin() in setup() for a single instrumented run. */

#include <Wire.h>

// ---- BUILD TOGGLES ----------------------------------------------------

#define SCHED_ENABLE 1 // Gain Scheduling

// ---- PINS -------------------------------------------------------------

#define ENC_L_A  2
#define ENC_L_B  4
#define ENC_R_A  3
#define ENC_R_B  5
#define AIN1     7
#define AIN2     8
#define PWM_L    9
#define PWM_R    10
#define BIN1     12
#define BIN2     13
#define STBY     6

// ---- SIGN CONVENTIONS -------------------------------------------------

#define THETA_SIGN   (+1.0f)
#define GYRO_SIGN    (+1.0f)
#define MOTOR_L_SIGN (-1)
#define MOTOR_R_SIGN (+1)
#define ENC_L_SIGN   (-1)
#define ENC_R_SIGN   (+1)

// ---- MEASURED CONSTANTS -----------------------------------------------

const float THETA_OFFSET   = 0.0365f;
const int   DEADBAND_L     = 19;
const int   DEADBAND_R     = 12;
const float COUNTS_PER_REV = 1000.0f;
const float WHEEL_RADIUS   = 0.0325f;
const float U_MAX          = 11.1f;
const float U_MIN          = 0.10f;

// ---- Initialze States -------------------------------------------------

float theta = 0, theta_dot = 0, theta_dot_f = 0;
float pos = 0, vel_f = 0;
float gyro_bias = 0;
volatile long encL = 0, encR = 0;
long enc_prev = 0;
bool armed = false, prev_armed = false;
unsigned long upright_since = 0, armed_at = 0, fell_at = 0;

// ---- CONTROLLER (State feedback gains) --------------------------------

const float K[4] = { 13.703f, 0.879f, 0.405f, 16.000f }; 

// Low-pass on the rate term only. The raw gyro is noisy enough that K[1]
// amplifies it into audible chatter. Costs phase lag - keep it as high as
// the chatter allows. 1.0 = off.
const float GYRO_LPF = 0.15f;

// K3 reaches K3_FAST once wheel speed hits V_BLEND. Delivered force falls
// with speed (back-EMF), so more velocity gain is needed when moving.
const float K3_FAST = 26.0f;
const float V_BLEND = 0.15f;

// ---- TIMING AND FILTERS -----------------------------------------------
// ALPHA is the complementary filter split: gyro integration dominates short
// term, accelerometer pulls out the long-term drift.
const int   LOOP_HZ = 200;
const float DT      = 1.0f / LOOP_HZ;
const unsigned long LOOP_US = 1000000UL / LOOP_HZ;
const float TAU     = 0.5f;
const float ALPHA   = TAU / (TAU + DT);
const float VEL_LPF = 0.15f;

// ---- ARM / DISARM -----------------------------------------------------

const float TILT_CUTOFF = 0.52f;
const float REARM_TILT  = 0.075f;
const unsigned long REARM_MS = 300;


// ---- IMU --------------------------------------------------------------

#define MPU_ADDR 0x68

void mpuWrite(uint8_t r, uint8_t v) {
  Wire.beginTransmission(MPU_ADDR); Wire.write(r); Wire.write(v);
  Wire.endTransmission();
}

// Reading bytes of the Imu
void mpuRead(float &ay, float &az, float &gx) {
  Wire.beginTransmission(MPU_ADDR); Wire.write(0x3B);
  Wire.endTransmission(false);
  Wire.requestFrom((uint8_t)MPU_ADDR, (uint8_t)14, (uint8_t)true);
  Wire.read(); Wire.read();
  int16_t ray = (Wire.read() << 8) | Wire.read();
  int16_t raz = (Wire.read() << 8) | Wire.read();
  Wire.read(); Wire.read();
  int16_t rgx = (Wire.read() << 8) | Wire.read();
  Wire.read(); Wire.read(); Wire.read(); Wire.read();
  ay = ray / 8192.0f;  az = raz / 8192.0f;  gx = rgx / 65.5f;
}

// ---- ENCODERS ---------------------------------------------------------

void isrL() { encL += (digitalRead(ENC_L_A) == digitalRead(ENC_L_B)) ? ENC_L_SIGN : -ENC_L_SIGN; }
void isrR() { encR += (digitalRead(ENC_R_A) == digitalRead(ENC_R_B)) ? ENC_R_SIGN : -ENC_R_SIGN; }


long encAvg() {
  long l, r;
  noInterrupts(); l = encL; r = encR; interrupts();
  return (l + r) / 2;
}

// ---- MOTORS -----------------------------------------------------------

// Force -> duty. Below U_MIN send nothing, else remap 0..255 onto
// deadband..255 so the smallest command still breaks static friction.
void setMotor(int pwmPin, int in1, int in2, float u, int deadband) {
  bool fwd = (u >= 0);
  float mag = fabsf(u);
  if (mag < U_MIN) { analogWrite(pwmPin, 0); return; }
  int duty = (int)((mag / U_MAX) * 255.0f);
  duty = map(duty, 0, 255, deadband, 255);
  duty = constrain(duty, 0, 255);
  digitalWrite(in1,  fwd);
  digitalWrite(in2, !fwd);
  analogWrite(pwmPin, duty);
}


void drive(float u) {
  u = constrain(u, -U_MAX, U_MAX);
  setMotor(PWM_L, AIN1, AIN2, MOTOR_L_SIGN * u, DEADBAND_L);
  setMotor(PWM_R, BIN1, BIN2, MOTOR_R_SIGN * u, DEADBAND_R);
}


void motorsOff() { analogWrite(PWM_L, 0); analogWrite(PWM_R, 0); }

// - ESTIMATOR (Turns raw sensors into the four states the control law needs.)-------------

void estimateAngle() { 
  float ay, az, gx;
  mpuRead(ay, az, gx);
  theta_dot    = GYRO_SIGN * (gx - gyro_bias) * PI / 180.0f;
  theta_dot_f += GYRO_LPF * (theta_dot - theta_dot_f);
  float theta_acc = THETA_SIGN * atan2f(ay, az);
  theta = ALPHA * (theta + theta_dot * DT) + (1 - ALPHA) * theta_acc;
}


void estimateCart() {
  const float M_PER_COUNT = (2.0f * PI * WHEEL_RADIUS) / COUNTS_PER_REV;
  long c = encAvg();
  float dpos = (c - enc_prev) * M_PER_COUNT;
  enc_prev = c;
  pos    = c * M_PER_COUNT;
  vel_f += VEL_LPF * ((dpos / DT) - vel_f);
}

// Zero the cart states. Called on arming so every run starts from x = 0.
void resetCart() {
  noInterrupts(); encL = 0; encR = 0; interrupts();
  enc_prev = 0; pos = 0; vel_f = 0;
}

// ---- CONFIG BANNER ----------------------------------------------------

// Printed at boot and again at the head of every dump, so a saved log
// carries the constants that produced it. Bias is passed in because the
// dump must report the bias from the run being dumped, not this boot.
void printConfig(float bias) {
  Serial.print(F("# BUILD ")); Serial.print(F(__DATE__));
  Serial.print(' ');           Serial.println(F(__TIME__));
  Serial.print(F("# gyro_bias ")); Serial.println(bias, 4);
  Serial.print(F("# offset ")); Serial.print(THETA_OFFSET, 4);
  Serial.print(F("  K ")); Serial.print(K[0], 3); Serial.print(' ');
  Serial.print(K[1], 3); Serial.print(' '); Serial.print(K[2], 3);
  Serial.print(' '); Serial.print(K[3], 3);
  Serial.print(F("  GYRO_LPF ")); Serial.println(GYRO_LPF, 2);
  Serial.print(F("# U_MAX ")); Serial.print(U_MAX, 2);
  Serial.print(F("  K3_FAST ")); Serial.print(K3_FAST, 1);
  Serial.print(F("  V_BLEND ")); Serial.print(V_BLEND, 2);
  Serial.print(F("  SCHED ")); Serial.println(SCHED_ENABLE);
}

// ---- TEST MODE --------------------------------------------------------

// Enable/disable: the testModeBegin() call in setup().
// Keep the battery connected when plugging in USB, or the data is lost.
// TEST_SAMPLES x 6 bytes comes out of the same 2 KB as the stack. Raising
// either define means bumping TEST_MAGIC, or a stale buffer of the old
// geometry gets read as valid.
// Trace looks like noise -> raise TEST_HZ, cut TEST_SECONDS to match.

#define TEST_SECONDS 6
#define TEST_HZ      25
#define TEST_SAMPLES (TEST_SECONDS * TEST_HZ)
#define TEST_DIV     (LOOP_HZ / TEST_HZ)
#define TEST_MAGIC   0xB102u


#define SC_ANG  10000.0f   // rad    -> +/-3.27 rad
#define SC_RATE  1000.0f   // rad/s  -> +/-32.7 rad/s
#define SC_U     1000.0f   // N      -> +/-32.7 N

int16_t  test_buf[TEST_SAMPLES][3] __attribute__((section(".noinit")));
uint16_t test_count __attribute__((section(".noinit")));
uint16_t test_magic __attribute__((section(".noinit")));
float    test_bias  __attribute__((section(".noinit")));

bool test_mode    = false;   
bool test_started = false;   
bool test_done    = false;   

int16_t testPack(float v, float scale) {
  long n = lroundf(v * scale);
  if (n >  32767L) n =  32767L;
  if (n < -32767L) n = -32767L;
  return (int16_t)n;
}


void testModeDump() {
  if (test_magic != TEST_MAGIC) return;
  if (test_count == 0 || test_count > TEST_SAMPLES) { test_magic = 0; return; }

  Serial.print(F("# ---- PREVIOUS RUN: "));
  Serial.print(test_count); Serial.print(F(" samples @ "));
  Serial.print(TEST_HZ);    Serial.println(F(" Hz ----"));
  printConfig(test_bias);
  Serial.println(F("# t_ms,e,theta_dot,u"));

  for (uint16_t i = 0; i < test_count; i++) {
    Serial.print((unsigned long)i * (1000UL / TEST_HZ)); Serial.print(',');
    Serial.print(test_buf[i][0] / SC_ANG,  4);           Serial.print(',');
    Serial.print(test_buf[i][1] / SC_RATE, 3);           Serial.print(',');
    Serial.println(test_buf[i][2] / SC_U,  3);
  }
  Serial.println(F("# ---- END ----"));

  test_magic = 0;
}


void testModeBegin() {
  testModeDump();
  test_mode = true; test_started = false; test_done = false;
  test_count = 0; test_magic = TEST_MAGIC;
  test_bias = gyro_bias;
  Serial.print(F("# TEST MODE - "));
  Serial.print(TEST_SECONDS); Serial.print(F(" s @ "));
  Serial.print(TEST_HZ);      Serial.println(F(" Hz, one run"));
}

bool testLockout() { return test_done; }


void testModeUpdate(float e, float u) {
  if (!test_mode || test_done) return;

  if (!armed) {
    if (test_started) test_done = true;   
    return;
  }
  test_started = true;

  if (millis() - armed_at >= (unsigned long)TEST_SECONDS * 1000UL) {
    test_done = true;
    armed = false;
    motorsOff();
    Serial.println(F("# ===== TEST RUN COMPLETE ====="));
    return;
  }

  static uint8_t tick = 0;
  if (++tick < TEST_DIV) return;
  tick = 0;
  if (test_count >= TEST_SAMPLES) return;

  test_buf[test_count][0] = testPack(e,           SC_ANG);
  test_buf[test_count][1] = testPack(theta_dot_f, SC_RATE);
  test_buf[test_count][2] = testPack(u,           SC_U);
  test_count++;
}

// ---- ARM / DISARM -----------------------------------------------------

void updateArming(float e) {
  
  if (testLockout()) { if (armed) { armed = false; motorsOff(); } return; }

  if (armed && fabsf(e) > TILT_CUTOFF) {
    armed = false; motorsOff(); upright_since = 0;
  } else if (!armed) {
    if (fabsf(e) < REARM_TILT) {
      if (upright_since == 0) upright_since = millis();
      if (millis() - upright_since > REARM_MS) {
        resetCart();
        armed = true;
      }
    } else upright_since = 0;
  }
}

// ---- CONTROLLER -------------------------------------------------------

float controlLaw(float e) {
  float k3 = K[3];
#if SCHED_ENABLE
  k3 += (K3_FAST - K[3]) * fminf(fabsf(vel_f) / V_BLEND, 1.0f);
#endif
  return K[0]*e + K[1]*theta_dot_f + K[2]*pos + k3*vel_f;
}

// ---- REPORTING --------------------------------------------------------

void reportTransitions() {
  if (armed == prev_armed) return;
  if (armed) {
    armed_at = millis();
    Serial.println(F("# ===== ARMED ====="));
  } else {
    fell_at = millis();
    Serial.print(F("# ===== FELL after "));
    Serial.print((fell_at - armed_at) / 1000.0f, 2);
    Serial.println(F(" s ====="));
  }
  prev_armed = armed;
}

// ---- SETUP ------------------------------------------------------------

void setup() {
  Serial.begin(115200);
  delay(300);   

  pinMode(AIN1, OUTPUT); pinMode(AIN2, OUTPUT);
  pinMode(BIN1, OUTPUT); pinMode(BIN2, OUTPUT);
  pinMode(PWM_L, OUTPUT); pinMode(PWM_R, OUTPUT);
  pinMode(STBY, OUTPUT); digitalWrite(STBY, HIGH);
  motorsOff();

  pinMode(ENC_L_A, INPUT_PULLUP); pinMode(ENC_L_B, INPUT_PULLUP);
  pinMode(ENC_R_A, INPUT_PULLUP); pinMode(ENC_R_B, INPUT_PULLUP);
  attachInterrupt(digitalPinToInterrupt(ENC_L_A), isrL, CHANGE);
  attachInterrupt(digitalPinToInterrupt(ENC_R_A), isrR, CHANGE);

  TCCR1B = (TCCR1B & 0b11111000) | 0x01;

  Wire.begin(); Wire.setClock(400000L);
  mpuWrite(0x6B, 0x00); delay(100);
  mpuWrite(0x1A, 0x03);
  mpuWrite(0x1B, 0x08);
  mpuWrite(0x1C, 0x08);
  delay(100);

  Serial.println(F("# hold still - calibrating"));
  float ay, az, gx, sum = 0;
  for (int i = 0; i < 1000; i++) { mpuRead(ay, az, gx); sum += gx; delay(2); }
  gyro_bias = sum / 1000.0f;

  mpuRead(ay, az, gx);
  theta = THETA_SIGN * atan2f(ay, az);

  printConfig(gyro_bias);

  // ---- TESTING MODE TOGGLE --------------------------------------------
  
  //testModeBegin(); // Uncomment for one instrumented run; comment out for normal operation. <------------------------
}

// ---- CONTROL LOOP -----------------------------------------------------

void loop() {
  
  static unsigned long next = micros();
  if ((long)(micros() - next) < 0) return;
  next += LOOP_US;
  if ((long)(micros() - next) > (long)LOOP_US) next = micros() + LOOP_US;

  estimateAngle();
  estimateCart();

  float e = theta - THETA_OFFSET;   // error about the true balance point
  updateArming(e);

  float u = 0;
  if (armed) { u = controlLaw(e); drive(u); }
  else       { motorsOff(); }

  reportTransitions();
  testModeUpdate(e, u);
}

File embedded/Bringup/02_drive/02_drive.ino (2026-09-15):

/* ============================================================================
 * balance.ino — state feedback balance controller
 *
 *   u = +K @ [theta, theta_dot, x, x_dot]
 *
 * Poles placed at [-15,-18,-0.7,-0.9] on the measured plant. The angle pair is
 * set above the +9.9 rad/s open-loop instability; the position pair is kept
 * deliberately slow so station-keeping does not fight the angle loop.
 *
 * Telemetry: t_ms,theta,e,theta_dot,x,x_dot,u,armed,overruns  at 50 Hz, 115200.
 * ========================================================================= */

#include <Wire.h>

// ---------------------------------------------------------------- pins
#define ENC_L_A  2
#define ENC_L_B  4
#define ENC_R_A  3
#define ENC_R_B  5
#define AIN1     7
#define AIN2     8
#define PWM_L    9
#define PWM_R    10
#define BIN1     12
#define BIN2     13
#define STBY     6

// ---------------------------------------------------------------- measured
#define THETA_SIGN     (+1.0f)
#define GYRO_SIGN      (+1.0f)
#define MOTOR_L_SIGN   (-1)
#define MOTOR_R_SIGN   (+1)
#define ENC_L_SIGN     (-1)
#define ENC_R_SIGN     (+1)

const float THETA_OFFSET = 0.092f;   // midpoint of the fwd/rev drift band
const int   DEADBAND_L   = 24;
const int   DEADBAND_R   = 18;
const float COUNTS_PER_REV = 1000.0f;
const float WHEEL_RADIUS   = 0.0325f; // 65 mm dia, measured on the robot
const float U_MAX          = 1.7f;    // N at full duty - measured, not datasheet
const float U_MIN          = 0.10f;   // N - below this, command nothing

const float M_PER_COUNT = (2.0f * PI * WHEEL_RADIUS) / COUNTS_PER_REV;

// ---------------------------------------------------------------- gains
// [theta, theta_dot, x, x_dot]
const float K[4] = { 23.57f, 1.20f, -0.96f, -2.56f };

// ---------------------------------------------------------------- loop
const int   LOOP_HZ = 200;
const float DT      = 1.0f / LOOP_HZ;
const unsigned long LOOP_US = 1000000UL / LOOP_HZ;

const float TAU   = 0.5f;
const float ALPHA = TAU / (TAU + DT);
const float VEL_LPF = 0.30f;

// Gyro low-pass for the CONTROL path only (~4.8 Hz). The robot shakes at about
// 25 Hz; unfiltered, K[1]*theta_dot was 97% of u and the loop fed its own
// vibration. The complementary filter still integrates the raw rate.
const float GYRO_LPF = 0.30f;

const float TILT_CUTOFF = 0.52f;   // rad (30 deg) - disarm past this
const float REARM_TILT  = 0.05f;   // rad (3 deg)
const unsigned long REARM_MS = 400;

// ---------------------------------------------------------------- state
float theta = 0, theta_dot = 0, theta_dot_f = 0, pos = 0, vel = 0, vel_f = 0;
float gyro_bias = 0;
volatile long encL = 0, encR = 0;
long enc_prev = 0;
bool armed = false;
bool prev_armed = false;
unsigned long upright_since = 0;
unsigned long armed_at = 0;
unsigned long fell_at = 0;
unsigned int overruns = 0;

// ---------------------------------------------------------------- MPU
#define MPU_ADDR 0x68

void mpuWrite(uint8_t r, uint8_t v) {
  Wire.beginTransmission(MPU_ADDR); Wire.write(r); Wire.write(v);
  Wire.endTransmission();
}

void mpuRead(float &ay, float &az, float &gx) {
  Wire.beginTransmission(MPU_ADDR); Wire.write(0x3B);
  Wire.endTransmission(false);
  Wire.requestFrom((uint8_t)MPU_ADDR, (uint8_t)14, (uint8_t)true);
  Wire.read(); Wire.read();                          // accel X
  int16_t ray = (Wire.read() << 8) | Wire.read();
  int16_t raz = (Wire.read() << 8) | Wire.read();
  Wire.read(); Wire.read();                          // temp
  int16_t rgx = (Wire.read() << 8) | Wire.read();
  Wire.read(); Wire.read(); Wire.read(); Wire.read();
  ay = ray / 8192.0f;  az = raz / 8192.0f;  gx = rgx / 65.5f;
}

// ---------------------------------------------------------------- encoders
void isrL() { encL += (digitalRead(ENC_L_A) == digitalRead(ENC_L_B)) ? ENC_L_SIGN : -ENC_L_SIGN; }
void isrR() { encR += (digitalRead(ENC_R_A) == digitalRead(ENC_R_B)) ? ENC_R_SIGN : -ENC_R_SIGN; }

long encAvg() {
  long l, r;
  noInterrupts(); l = encL; r = encR; interrupts();   // 32-bit reads not atomic
  return (l + r) / 2;
}

// ---------------------------------------------------------------- motors
void setMotor(int pwmPin, int in1, int in2, float u, int deadband) {
  bool fwd = (u >= 0);
  float mag = fabsf(u);
  // Below U_MIN, command nothing. Without this the deadband map jumps any
  // non-zero u straight to duty=deadband, so near upright the motors slam
  // between +/-deadband every loop and chatter instead of controlling.
  if (mag < U_MIN) { analogWrite(pwmPin, 0); return; }
  int duty = (int)((mag / U_MAX) * 255.0f);
  duty = map(duty, 0, 255, deadband, 255);                 // skip the dead zone
  duty = constrain(duty, 0, 255);
  digitalWrite(in1,  fwd);
  digitalWrite(in2, !fwd);
  analogWrite(pwmPin, duty);
}

void drive(float u) {
  u = constrain(u, -U_MAX, U_MAX);
  setMotor(PWM_L, AIN1, AIN2, MOTOR_L_SIGN * u, DEADBAND_L);
  setMotor(PWM_R, BIN1, BIN2, MOTOR_R_SIGN * u, DEADBAND_R);
}

void motorsOff() { analogWrite(PWM_L, 0); analogWrite(PWM_R, 0); }

// ---------------------------------------------------------------- setup
void setup() {
  Serial.begin(115200);

  pinMode(AIN1, OUTPUT); pinMode(AIN2, OUTPUT);
  pinMode(BIN1, OUTPUT); pinMode(BIN2, OUTPUT);
  pinMode(PWM_L, OUTPUT); pinMode(PWM_R, OUTPUT);
  pinMode(STBY, OUTPUT); digitalWrite(STBY, HIGH);
  motorsOff();

  pinMode(ENC_L_A, INPUT_PULLUP); pinMode(ENC_L_B, INPUT_PULLUP);
  pinMode(ENC_R_A, INPUT_PULLUP); pinMode(ENC_R_B, INPUT_PULLUP);
  attachInterrupt(digitalPinToInterrupt(ENC_L_A), isrL, CHANGE);
  attachInterrupt(digitalPinToInterrupt(ENC_R_A), isrR, CHANGE);

  TCCR1B = (TCCR1B & 0b11111000) | 0x01;    // ~31 kHz PWM on D9/D10

  Wire.begin(); Wire.setClock(400000L);
  mpuWrite(0x6B, 0x00); delay(100);
  mpuWrite(0x1A, 0x03);                     // gyro DLPF 44 Hz
  mpuWrite(0x1B, 0x08);                     // +/-500 deg/s
  mpuWrite(0x1C, 0x08);                     // +/-4g
  delay(100);

  Serial.println(F("# hold still - calibrating"));
  float ay, az, gx, s = 0;
  for (int i = 0; i < 1000; i++) { mpuRead(ay, az, gx); s += gx; delay(2); }
  gyro_bias = s / 1000.0f;

  mpuRead(ay, az, gx);
  theta = THETA_SIGN * atan2f(ay, az);

  Serial.print(F("# gyro_bias ")); Serial.println(gyro_bias, 4);
  Serial.println(F("# t_ms,theta,e,theta_dot,x,x_dot,u,armed,overruns"));
}
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

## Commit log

2026-06-01 Stage 0: pendulum simulation with PID control and documented results
2026-06-01 update root read me to show stage 0 analysis
2026-06-02 Stage 1: implement coupled cart-pole dynamics, document unstable angle only PID result
2026-06-02 Stage 1: coupled cart-pole dynamics, cascaded PID, pole placement, state feedback
2026-06-14 Add Stage 2 CAD source files (design as-modelled, print validation pending)
    [chassis_assembly.SLDASM, platform.SLDPRT]
2026-08-06 Fix cart-pole model errors and regenerate Stage 1 results
    Gravity coefficients were transposed between the theta and x rows of the
    linearised A matrix, giving an open loop unstable pole of 1.533 rad/s against
    a true value of 6.220. Damping and centrifugal terms carried incorrect signs
    in both the nonlinear model and the hand derivation.
    Errors identified through a dimensional consistency check on the pendulum
    equation and a physical sanity check on the open loop pole (a free cart must
    fall faster than a fixed pivot, not slower). Verified against an independent
    Lagrangian derivation.
    Regenerated K = [57.33, 8.15, -11.01, -10.83]. State feedback now settles in
    2.5s with 0.08m peak cart displ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
2026-08-06 Update root README: broaden scope beyond PID, add state-feedback and pole placement to skills, expand setup instructions
2026-08-07 Stage 0 and 1 READMEs update, fix punctuation errors and analysis gaps
2026-09-02 Stage 0 README.md note that parameters are nominal, fix punctuation consistency
2026-09-02 Clarify stage definitons
2026-09-02 Add stage 2 hardware documentation: mechanical design section drafted, electronics and parameters pending
    [chassis_assembly.SLDASM, platform.SLDPRT]
2026-09-03 Finish README for stage 2, all except for physical parameters
2026-09-03 Add stage 2 results in root README
2026-09-03 Add stage 2 Build picutre and parameters
2026-09-04 Fully update stage 2 README, move onto stage 3
2026-09-15 Add stage 3 and fix grammer and punctuation errors
    [01_imu.ino, 02_drive.ino, 03_umax_accel.ino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]
2026-09-15 Change structure in stage 3
